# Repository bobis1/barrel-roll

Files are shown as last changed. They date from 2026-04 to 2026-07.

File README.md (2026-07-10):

# barrel-roll

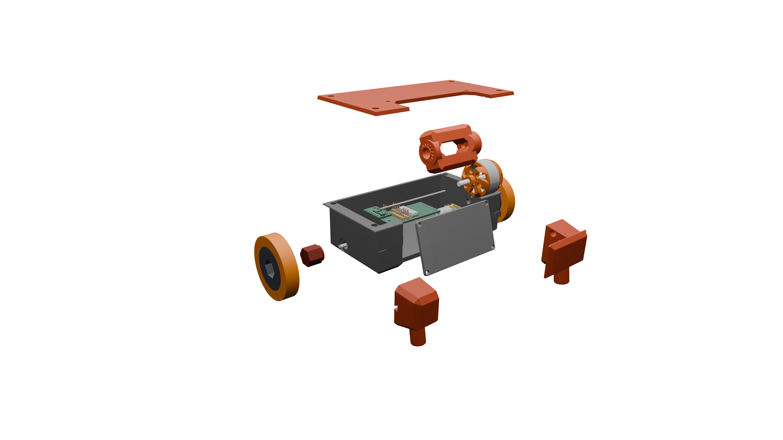
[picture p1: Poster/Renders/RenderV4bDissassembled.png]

_Slightly dissassembled view of barrel roll._

Currently there are some issues with this project
## TODO
- Fix the pcb to have the correct footprint

## What is this
Barrel roll is a 150g combat robot that has a 2.706693 inch long bar spinner. There are two options for the microcontroller of the robot. Right now I have a pcb designed with a RP2040 in mind. I also have a version of the schematic/firmware with an esp32 as the microcontroller.

## Why I created this
I created barrel roll because the way I got into robotics/programming/stem in general is through watching various battlebots-like shows and videos on the internet. So for a long time, I wanted to create my own battle bot. Once I saw the Fallout event by Hack Club I decided that it would be an amazing opportunity to create something similar to what got me into this in the first place. My goal with barrel roll is to create a bar spinner battle bot that could compete in the 150g weight class.(not necessarily well)

## PCB
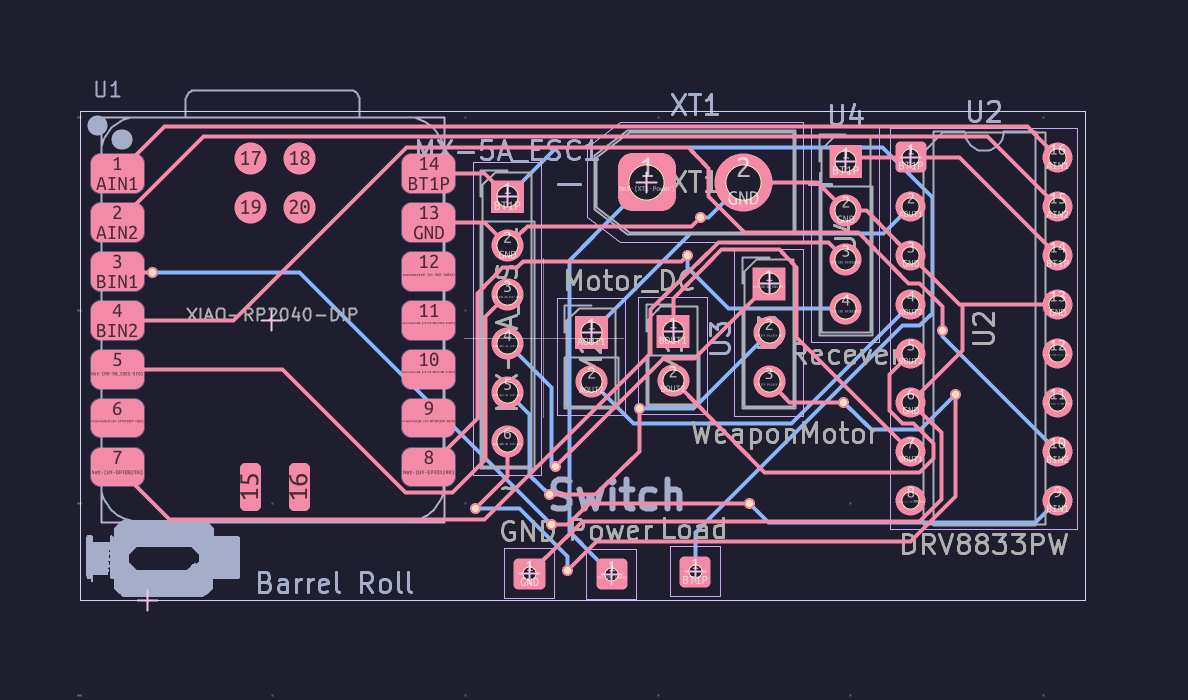
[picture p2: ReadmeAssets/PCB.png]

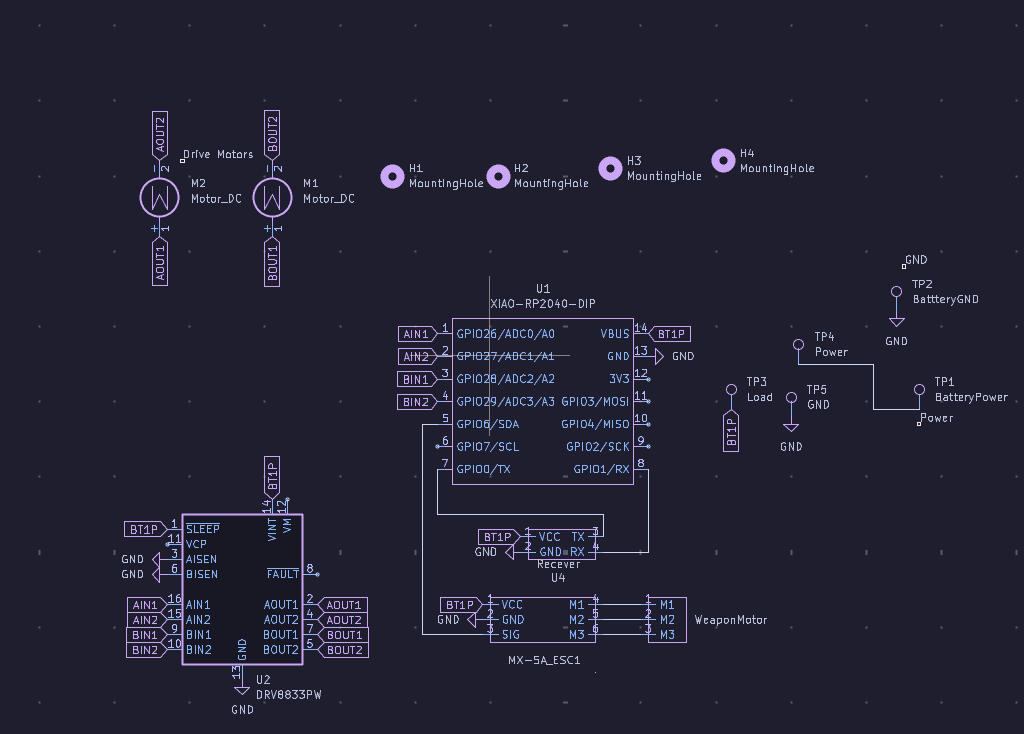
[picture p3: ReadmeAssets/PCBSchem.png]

Above are the images of the PCB version of the electrical components of the robot(To be honest right now it feels more like a glorified pinout board)

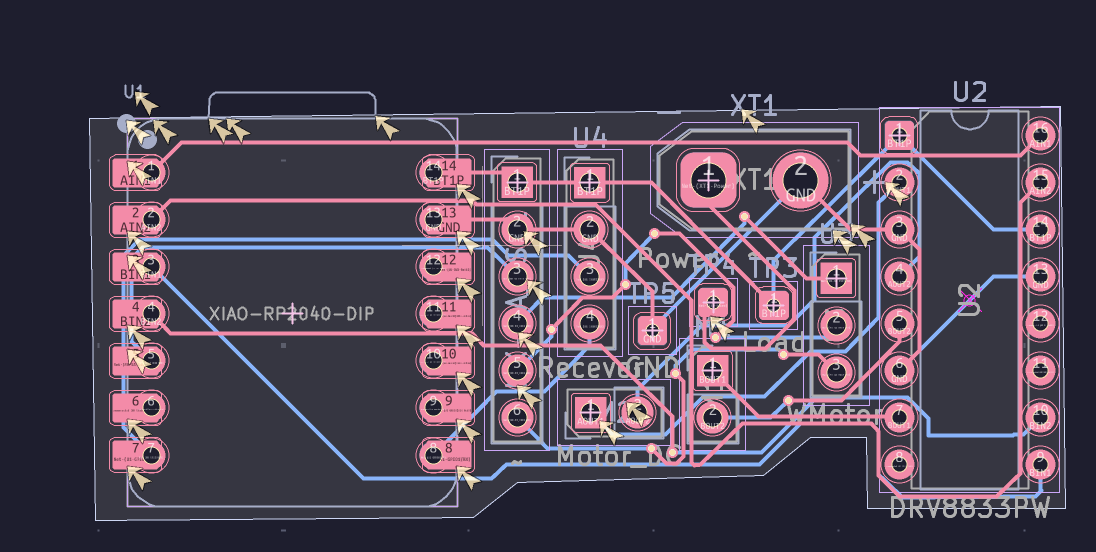
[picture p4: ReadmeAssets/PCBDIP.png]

Above is a picture of the pcb using DIP sodering. The schematic is the same as the original SMD sodered PCB.

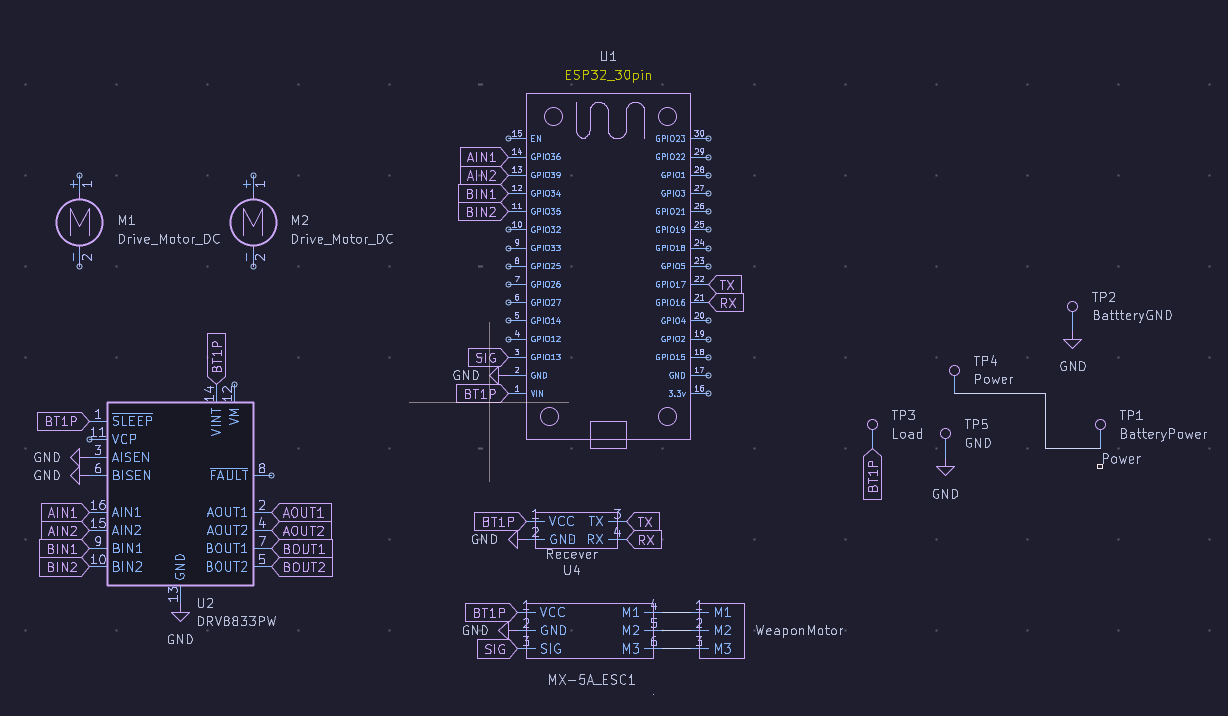
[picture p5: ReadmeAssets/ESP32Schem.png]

The above is a picture of the schematic for anyone using the DOIT esp32 devkit v1. I made this one because it could cut down on the cost of the project as a whole.

## Assembly
Onshape link: https://cad.onshape.com/documents/4d0cf8c11fd66439fc3e30b0/w/a8064dfad10d7d33689fe150/e/62081654516d84e6ca0ee160
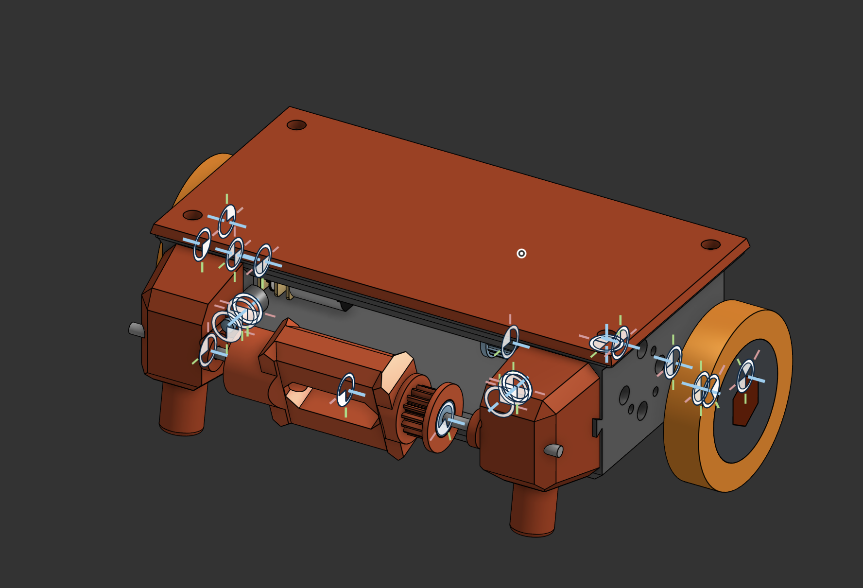
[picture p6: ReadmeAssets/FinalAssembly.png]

A note about the assembly: I could not find 3d models of the bearings I wanted to use so I made a model with the same dimensions as the bearings. /n

As a note I intend on using the PCB SMD BOM.

### PCBs/Electronics
For this project I made several usable versions of the electronics. I did this to make sure that when it comes time for me to actually build this I can still build it even if I don't have some of the equipment that I need. The main distinction between all of the options are the different ways to soder on the microcontroller. For the no pcb method you could just use an esp32 instead of a xiao rp2040.

#### PCB SMD
IF you are using a PCB to create Barrel Roll then you need to get the Gerbers.zip from barrel-roll folder in the repo. After this you need to go to your preferred PCB manufacteror of your choice to have it manufactured.  [Gerbers.zip](barrel-roll-pcb/Gerbers.zip)
You could use [this](https://fabacademy.org/2024/labs/charlotte/students/richard-shan/lessons/week4/rp2040/) as a reference for SMD sodering the xiao RP2040.

#### PCB DIP
If you are using the DIP version of the pcb then you need to follow many of the same steps as using the SMD pcb method. However, since you are using DIP for the RP2040, sodering the PCB should be significantly simpler. [Gerbers.zip](barrel-roll-DIPPCB/Gerbers.zip)

#### No PCB
If you are not using a PCB your costs will be a little bit lower since you don't need to by the PCB. To find the wiring diagram you can look in the barrel-roll-nopcb folder of the repo. This is a kicad project that contains a wiring diagram if you have a DOIT ESP32 devkit 1(The esp32 from the electronics kits that commonly come from hackclub events).

#### Assembling the weapon system shell
In order to assemble the weapon system properly you want to make sure that you place the parts on the axle in the correct order. Axle stopper, Weapon with bearing, Axle stopper. Then you need to place the axle onto the two pieces on the Side shell.
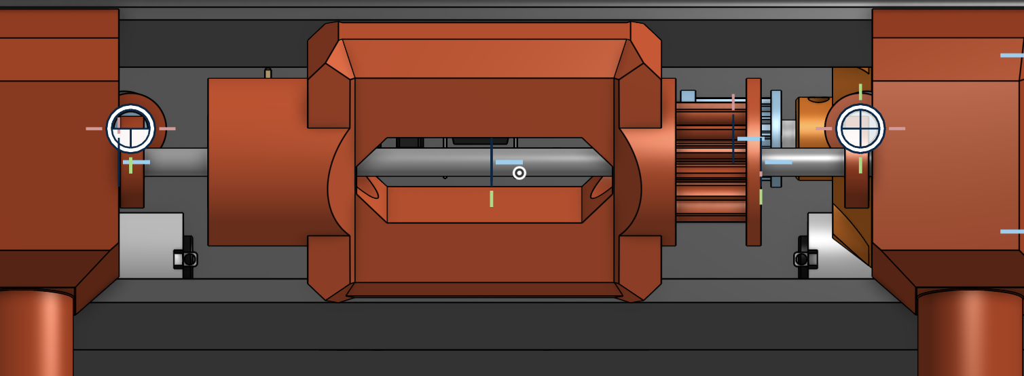
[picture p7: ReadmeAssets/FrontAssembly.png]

Here is a picture of the front assembly that you should try to replicate.

#### 3D printing
To assemble the barrel-roll you first need to print out the parts specified in the onshape document. All the parts in the FINAL folder must be printed There will be a note with the quantity and the infill amount. The fillament for all of these will be up to you. I will personally be using TPU. If you do not want to go into the Onshape, All of the final .step files will be in [models/FinalParts](CAD/V5).\

 You need to print:
* 1 BodyFinalPart1.step [Link](CAD/V5/BodyFinalPart1.step)
* 1 BodyFinalPart2.step [Link](CAD/V5/BodyFinalPart2.step)
* 2 n20motorToWheel.step [Link](CAD/V5/n20motorToWheel.step)
* 1 ShaftCap [Link](CAD/V5/ShaftCapFinal.step)
* 1 WeaponDirectDrive.step [Link](CAD/V5/WeaponDirectDrive.step)
* Weapon Cap [Link](CAD/V5/WeaponMotorCap.step)

#### Assembling the shell
##### For context:
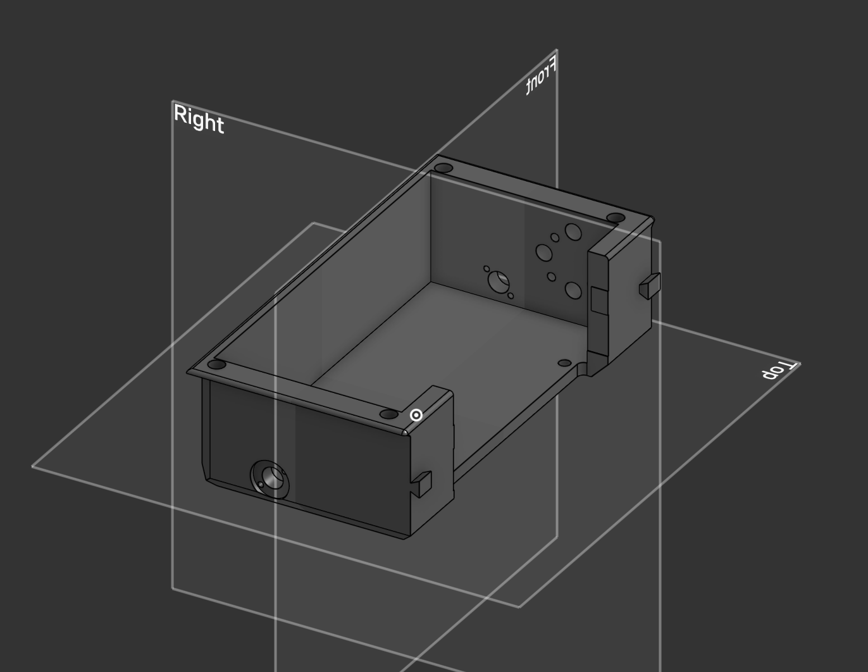
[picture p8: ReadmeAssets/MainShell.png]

[.Step File](CAD/V5/BodyFinalPart1.step)
The above is the main shell
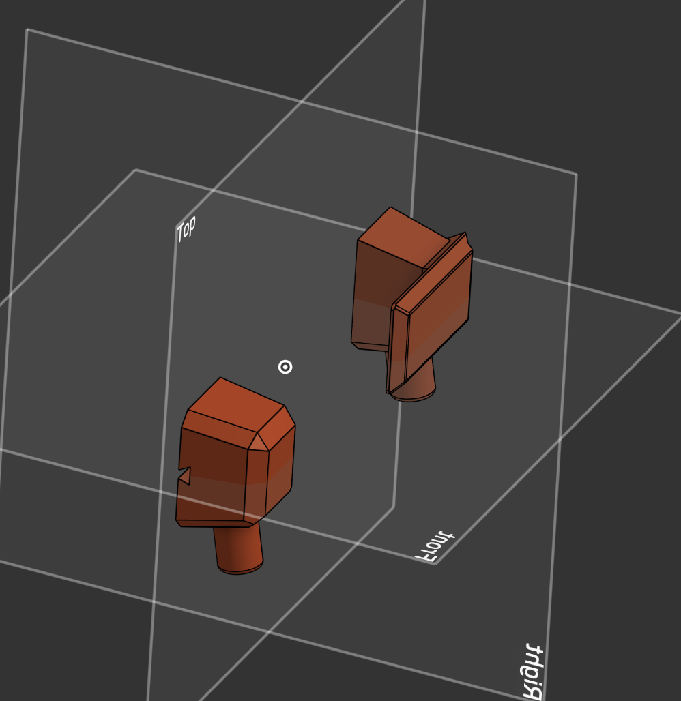
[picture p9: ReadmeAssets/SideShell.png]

[.Step File](CAD/V5/BodyFinalPart2.step)

The above is the side shell
For the rest of it you should look at the onshape document.

To assemble the Main shell with the Side Shells you can use the bowtie connector along side the fastening rod to attach each part of the SIDE_SHELL without the use of metal connectors. To do this, follow the instructions below.

- 1. you first need to slide the shell into place directly into the bowtie connector. The next thing you want to do is slot in the pin connectors into the respective hole.
 [video](ReadmeAssets/SideAssembly1.mov). (Yes I knbow the video is outdated I made the video before making a bunch of design changes relating to the side shell.)

- 2. After this you want to slide the shaft onto the side piece. The next thing that you want to do is attach a shaft cap directly on the inside of the side shell. [video](ReadmeAssets/ShaftAssembly1.mov). 

- 3. You need to slide the weapon onto the shaft. Next you need to slide the other shaft cap onto the shaft.
[video](ReadmeAssets/ShaftAssembly2.mov). After you do this you need to attach the belt to the timing wheel of the weapon.

- 4. The next thing that you need to do is you need to repeat step 1 for the other side of the case. With this you are finished with the shell assembly.

#### Assembling the weapon motor system
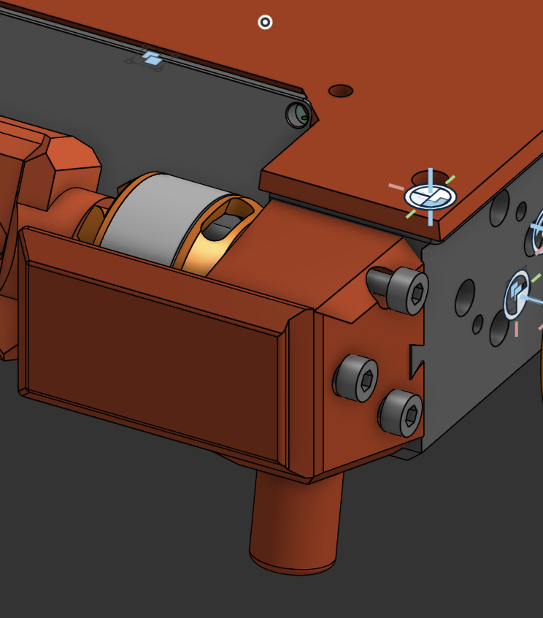
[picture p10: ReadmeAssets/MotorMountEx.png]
motorMountAssembly
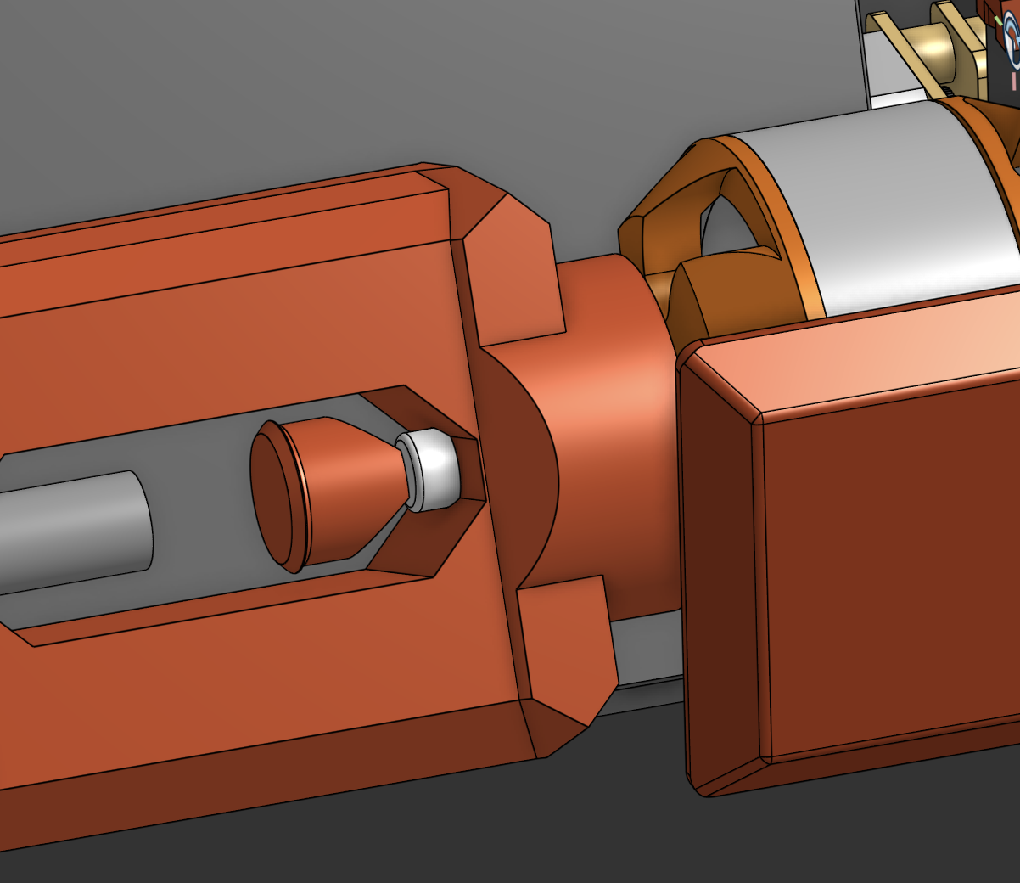
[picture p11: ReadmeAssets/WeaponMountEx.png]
WeaponAssembly
Assemblint the weapon system involves, using the weapon motor screws to secure the motor to the side of the shell with the "shield" like so . Next to finish securing the weapon onto the motor, simply slide the weapon onto the motor shaft then place the cap onto the motor shaft like so .
With this you are almost done with the weapon motor system. n/

The next thing that you need to do is slide the shaft into the bearings. Before doing this you need to cut the (90mm) shaft into a 60mm shaft.(The reason for this is to cut down on the weight and to to make the shaft super long.) An alternative to this would be to print out a similarly sized rod out of ABS or petg [Here](CAD/V5/shaft.step)

#### Electronics
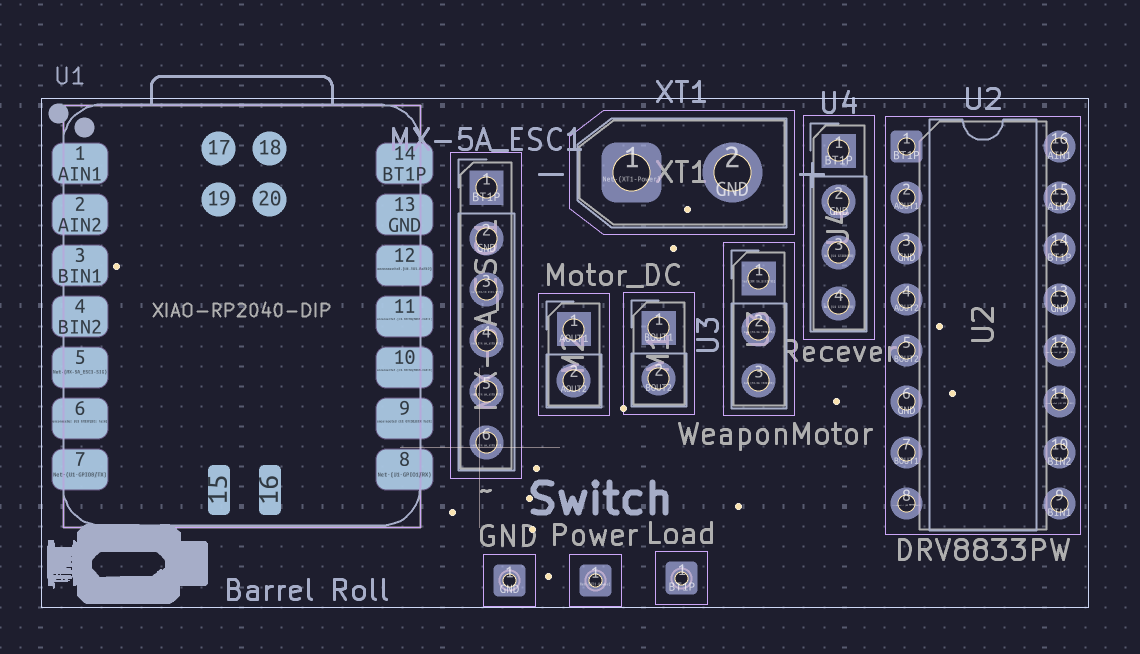
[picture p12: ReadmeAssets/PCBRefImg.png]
PCB image
For the electronics you want to reference the [Schematic](ReadmeAssets/barrel-roll.pdf) and the . First you want to wire the drive motors to AOUT and BOUT pin holes respectively. Do this for both of the drive motors. The next thing that you want to do is attach the motor driver to the respective pins. Next you have to attach the ESC motor controller for the brushless motor. Next you have to soder the jumper wires to their respective ports based on the schematic of the pcb. The schematic should have all the pins that you need to soder to.

## Usage
To use barrel roll you need to connect the radio recever to the radio sender.
After this you should be able to control the robot using your controller.

## BOM
There are three BOMs one for SMD, DIP and one if you are simply using a esp32.
The "master" BOM can be found here [BOM](ReadmeAssets/BOM.csv)(This will be the most convienient to use and will be the most updated in the coming months.)
### BOM for PCB
 [Here is the .csv for the BOM](ReadmeAssets/BarrelRollerBOM.csv)
### BOM if you are not using a PCB
 [Here is the .csv for the BOM](ReadmeAssets/BarrelRollerBOMnopcb.csv)
### BOM PCB-DIP
 [Here is the .csv for the BOM](ReadmeAssets/BarrelRollerBOMDIP.csv)

## Poster
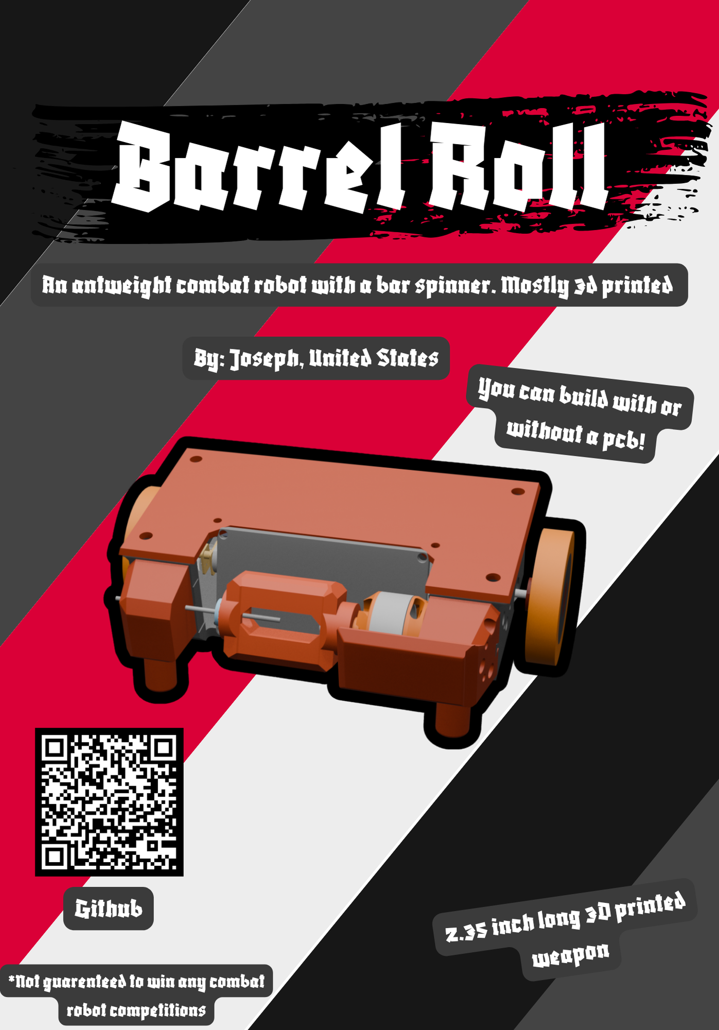
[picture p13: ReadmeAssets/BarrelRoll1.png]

[Poster](Poster/Barrel%20Roller.pdf)

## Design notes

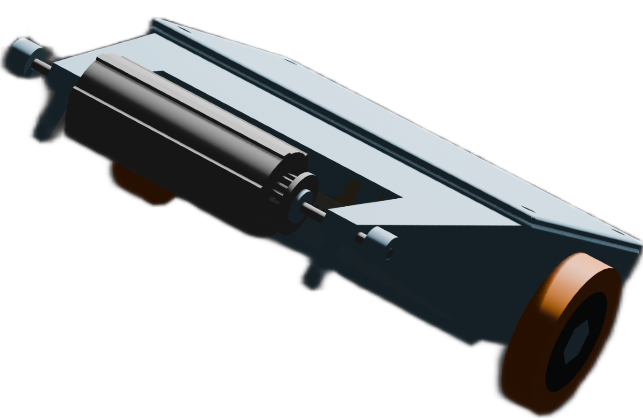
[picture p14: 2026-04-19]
Poster/Renders/FinalRenderNoback.png

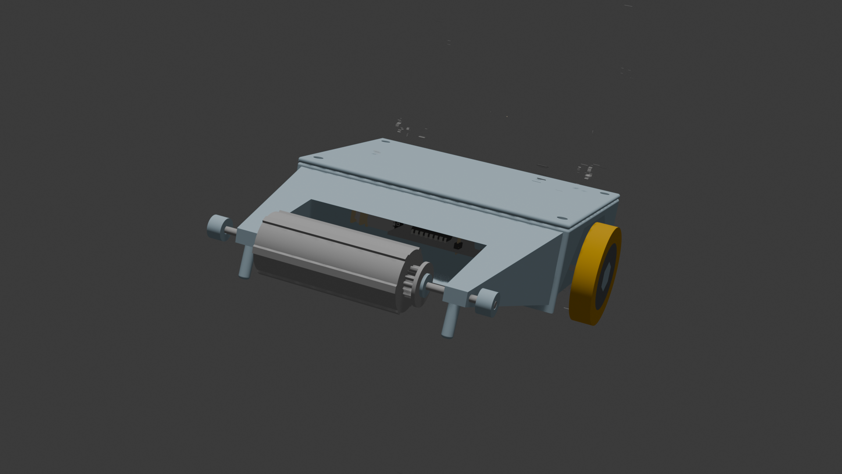
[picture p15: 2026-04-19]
Poster/Renders/DraftRender1.png

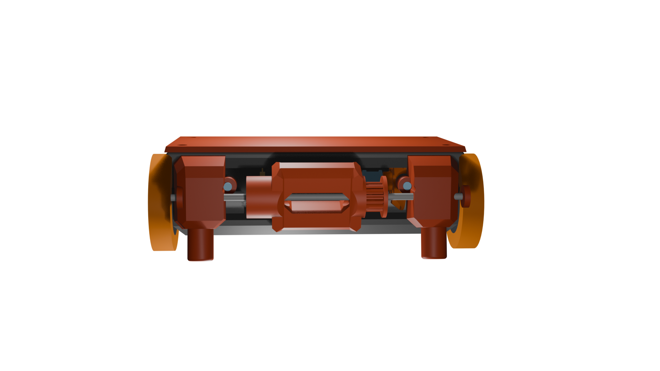
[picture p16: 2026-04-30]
Poster/Renders/RenderV2.png

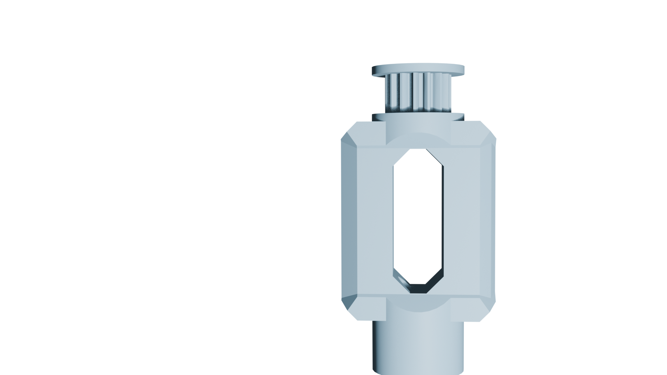
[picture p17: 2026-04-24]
Poster/Renders/PCBWeaponRender1.png

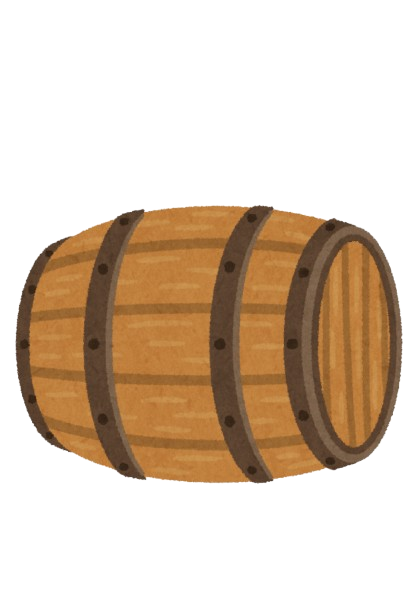
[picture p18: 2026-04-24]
Poster/assets/Barrel_Roller__1_-removebg-preview.png

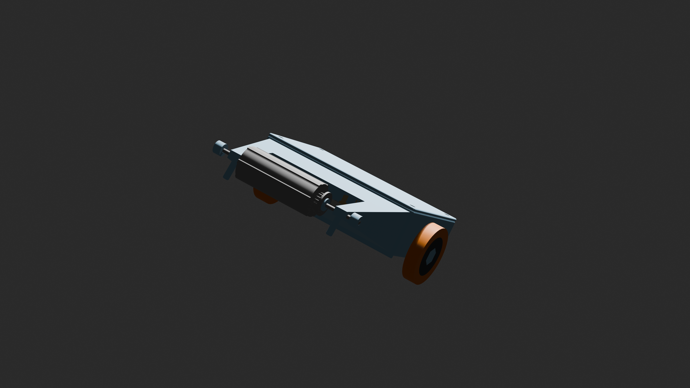
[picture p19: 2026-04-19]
Poster/Renders/FinalRender.png

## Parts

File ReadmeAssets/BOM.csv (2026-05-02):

Barrel-roll-SMDPCB
Reference | Qty | Part | Footprint | Supplier | Unit Price | Total Price | Weight | SubTotal: | $234.90
U1 | 1 | XIAO-RP2040-DIP | Seeed Studio XIAO Series Library:XIAO-RP2040-DIP | https://www.seeedstudio.com/XIAO-RP2040-v1-0-p-5026.html | $3.99 | $3.99 |  | Shipping: | $35.37
U2 | 1 | DRV8833PW | Package_DIP:DIP-16_W7.62mm | https://www.pololu.com/product/2130/resources | $10.95 | $10.95 |  | Tax: | $4.05
U3 | 1 | WeaponMotor | Connector_PinHeader_2.54mm:PinHeader_1x03_P2.54mm_Vertical | https://itgresa.com/product/d2822-8-brushless-motor-outrunner/ | $15.49 | $15.49 |  | Total: | $274.32
U4 | 1 | Recever | Connector_PinHeader_2.54mm:PinHeader_1x04_P2.54mm_Vertical | https://radiomasterrc.com/collections/elrs-receivers/products/xr1-nano-multi-frequency-expresslrs-receiverr | $11.99 | $11.99 |  | Hours Required: | 54.86
n/a | 2 | Bearings | n/a | https://www.aliexpress.us/item/2271799817221155.html?curPageLogUid=5TuNOIFeizbl | $0.65 | $1.30
n/a | 1 | Shaft | n/a | https://www.aliexpress.us/item/3256805290944526.html?curPageLogUid=UdRs5Z1uZKiS | $0.99 | $0.99
n/a | 1 | Heatset Inserts | n/a | https://www.aliexpress.us/item/3256807895940353.html?curPageLogUid=BxN9cLGVkdYJ | $0.99 | $0.99
n/a | 1 | LIPO battery | Connector_Wire:SolderWire-2sqmm_1x01_D2mm_OD3.9mm | https://www.racedayquads.com/products/rdq-series-11-4v-3s-720mah-100c-lihv-whoopmicro-battery-xt30 | $18.49 | $18.49
XT1 | 1 | XT60 | Connector_AMASS:AMASS_XT30UPB-F_1x02_P5.0mm_Vertical | https://www.pololu.com/product/2175 | $2.95 | $2.95
n/a | 2 | N20 Motor | dc_motor | https://www.aliexpress.us/item/2255800106854951.html?curPageLogUid=DiJwBbgZZ32D | 0.99 | $1.98
n/a | 1 | PCB | n/a | n/a | $2.10 | $2.10
n/a | 1 | Weapon Motor Screws | n/a | https://www.homedepot.com/p/Everbilt-M3-0-5-x-12mm-Zinc-Flat-Head-Phillips-Drive-Machine-Screw-4-Pieces-837751/321071710 | $1.95 | $1.95
n/a | 4 | Drive Motor Screw | n/a | https://www.metricscrews.us/index.php?main_page=product_info&cPath=98_290_337&products_id=1240 | $0.65 | $2.60
n/a | 1 | Timing Belt | n/a | https://www.aliexpress.us/item/3256806230097622.html?curPageLogUid=Dl3947EX6SHI | $3.23 | $3.23
Barrel-roll-DIPPCB
Reference | Qty | Part | Footprint | Supplier | Unit Price | Total Price | Weight | SubTotal: | $155.90
U1 | 1 | XIAO-RP2040-DIP | Seeed Studio XIAO Series Library:XIAO-RP2040-DIP | https://www.seeedstudio.com/XIAO-RP2040-v1-0-p-5026.html | $3.99 | $3.99 |  | Shipping: | $35.37
U2 | 1 | DRV8833PW | Package_DIP:DIP-16_W7.62mm | https://www.pololu.com/product/2130/resources | $10.95 | $10.95 |  | Tax: | $4.05
U3 | 1 | WeaponMotor | Connector_PinHeader_2.54mm:PinHeader_1x03_P2.54mm_Vertical | https://itgresa.com/product/d2822-8-brushless-motor-outrunner/ | $15.49 | $15.49 |  | Total: | $195.32
U4 | 1 | Recever | Connector_PinHeader_2.54mm:PinHeader_1x04_P2.54mm_Vertical | https://radiomasterrc.com/collections/elrs-receivers/products/xr1-nano-multi-frequency-expresslrs-receiverr | $11.99 | $11.99 |  | Hours Required: | 39.06
n/a | 2 | Bearings | n/a | https://www.aliexpress.us/item/2271799817221155.html?curPageLogUid=5TuNOIFeizbl | $0.65 | $1.30
n/a | 1 | Shaft | n/a | https://www.aliexpress.us/item/3256805290944526.html?curPageLogUid=UdRs5Z1uZKiS | $0.99 | $0.99
n/a | 1 | Heatset Inserts | n/a | https://www.aliexpress.us/item/3256807895940353.html?curPageLogUid=BxN9cLGVkdYJ | $0.99 | $0.99
n/a | 1 | LIPO battery | Connector_Wire:SolderWire-2sqmm_1x01_D2mm_OD3.9mm | https://www.racedayquads.com/products/rdq-series-11-4v-3s-720mah-100c-lihv-whoopmicro-battery-xt30 | $18.49 | $18.49
XT1 | 1 | XT60 | Connector_AMASS:AMASS_XT30UPB-F_1x02_P5.0mm_Vertical | https://www.pololu.com/product/2175 | $2.95 | $2.95
n/a | 2 | N20 Motor | dc_motor | https://www.aliexpress.us/item/2255800106854951.html?curPageLogUid=DiJwBbgZZ32D | 0.99 | $1.98
n/a | 1 | PCB | n/a | n/a | $2.10 | $2.10
n/a | 1 | Weapon Motor Screws | n/a | https://www.homedepot.com/p/Everbilt-M3-0-5-x-12mm-Zinc-Flat-Head-Phillips-Drive-Machine-Screw-4-Pieces-837751/321071710 | $1.95 | $1.95
n/a | 4 | Drive Motor Screw | n/a | https://www.metricscrews.us/index.php?main_page=product_info&cPath=98_290_337&products_id=1240 | $0.65 | $2.60
n/a | 1 | Timing Belt | n/a | https://www.aliexpress.us/item/3256806230097622.html?curPageLogUid=Dl3947EX6SHI | $3.23 | $3.23
Barrel-roll-nopcb
Reference | Qty | Part | Footprint | Supplier | Unit Price | Total Price |  | SubTotal: | $76.91
U1 | 1 | XIAO-RP2040-DIP | DOIT Esp32 devkit v1 | https://www.aliexpress.us/item/3256805168037961.html?curPageLogUid=5MpwdTl1HOht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 | $4.00 | $4.00 |  | Shipping: | $35.37
U2 | 1 | DRV8833PW | Package_DIP:DIP-16_W7.62mm | https://www.pololu.com/product/2130/resources | $10.95 | $10.95 |  | Tax: | $4.05
U3 | 1 | WeaponMotor | Connector_PinHeader_2.54mm:PinHeader_1x03_P2.54mm_Vertical | https://itgresa.com/product/d2822-8-brushless-motor-outrunner/ | $15.49 | $15.49 |  | Total: | $116.33
U4 | 1 | Recever | Connector_PinHeader_2.54mm:PinHeader_1x04_P2.54mm_Vertical | https://radiomasterrc.com/collections/elrs-receivers/products/xr1-nano-multi-frequency-expresslrs-receiverr | $11.99 | $11.99 |  | Hours Required: | 23.27
n/a | 2 | Bearings | n/a | https://www.aliexpress.us/item/2271799817221155.html?curPageLogUid=5TuNOIFeizbl | $0.65 | $1.30
n/a | 1 | Shaft | n/a | https://www.aliexpress.us/item/3256805290944526.html?curPageLogUid=UdRs5Z1uZKiS | $0.99 | $0.99
n/a | 1 | Heatset Inserts | n/a | https://www.aliexpress.us/item/3256807895940353.html?curPageLogUid=BxN9cLGVkdYJ | $0.99 | $0.99
n/a | 1 | LIPO battery | Connector_Wire:SolderWire-2sqmm_1x01_D2mm_OD3.9mm | https://www.racedayquads.com/products/rdq-series-11-4v-3s-720mah-100c-lihv-whoopmicro-battery-xt30 | $18.49 | $18.49
XT1 | 1 | XT60 | Connector_AMASS:AMASS_XT30UPB-F_1x02_P5.0mm_Vertical | https://www.pololu.com/product/2175 | $2.95 | $2.95
n/a | 2 | N20 Motor | dc_motor | https://www.aliexpress.us/item/2255800106854951.html?curPageLogUid=DiJwBbgZZ32D | $0.99 | $1.98
n/a | 1 | Timing Belt | n/a | https://www.aliexpress.us/item/3256806230097622.html?curPageLogUid=Dl3947EX6SHI | $3.23 | $3.23
n/a | 1 | Weapon Motor Screws | n/a | https://www.homedepot.com/p/Everbilt-M3-0-5-x-12mm-Zinc-Flat-Head-Phillips-Drive-Machine-Screw-4-Pieces-837751/321071710 | $1.95 | $1.95
n/a | 4 | Drive Motor Screw | n/a | https://www.metricscrews.us/index.php?main_page=product_info&cPath=98_290_337&products_id=1240 | $0.65 | $2.60

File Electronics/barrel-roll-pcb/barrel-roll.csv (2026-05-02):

Reference | Qty | Value | DNP | Exclude from BOM | Exclude from Board | Footprint | Datasheet
M1,M2 | 2 | Motor_DC |  |  |  | Connector_PinHeader_2.54mm:PinHeader_1x02_P2.54mm_Vertical
MX-5A_ESC1 | 1 |  |  |  |  | Connector_PinHeader_2.54mm:PinHeader_1x06_P2.54mm_Vertical
TP1 | 1 | BatteryPower |  |  |  | Connector_Wire:SolderWire-2sqmm_1x01_D2mm_OD3.9mm
TP2 | 1 | BattteryGND |  |  |  | Connector_Wire:SolderWire-2sqmm_1x01_D2mm_OD3.9mm
TP3 | 1 | Load |  |  |  | Connector_Wire:SolderWire-0.1sqmm_1x01_D0.4mm_OD1mm
TP4 | 1 | Power |  |  |  | Connector_Wire:SolderWire-0.1sqmm_1x01_D0.4mm_OD1mm
TP5 | 1 | GND |  |  |  | Connector_Wire:SolderWire-0.1sqmm_1x01_D0.4mm_OD1mm
U1 | 1 | XIAO-RP2040-DIP |  |  |  | Seeed Studio XIAO Series Library:XIAO-RP2040-DIP
U2 | 1 | DRV8833PW |  |  |  | Package_DIP:DIP-16_W7.62mm | http://www.ti.com/lit/ds/symlink/drv8833.pdf
U3 | 1 | WeaponMotor |  |  |  | Connector_PinHeader_2.54mm:PinHeader_1x03_P2.54mm_Vertical
U4 | 1 | Recever |  |  |  | Connector_PinHeader_2.54mm:PinHeader_1x04_P2.54mm_Vertical

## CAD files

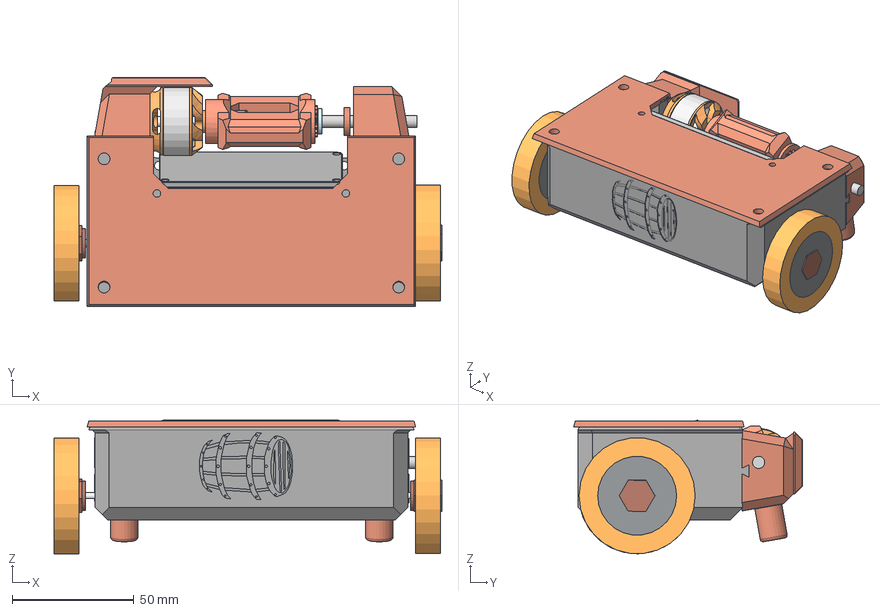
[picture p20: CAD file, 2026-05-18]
CAD/FinalAssembly/FinalAssembly.step
159.1 x 93.8 x 54.9 mm
Bearing
D2822-17 1100KV x 4
Shaft x 2
drv8833-dual-motor-driver-carrier-step
Gear Box x 16
DIP-16_W7.62mm
PinHeader_1x04_P2.54mm_Vertical
40A wheel x 2
WeaponSystem x 2
PinHeader_1x02_P2.54mm_Vertical
WeaponMotorCap
T40 hub x 2
PinHeader_1x02_P2.54mm_Vertical_1
PinHeader_1x03_P2.54mm_Vertical
PinHeader_1x06_P2.54mm_Vertical
Motor x 2
ElectronicsGuard
WeaponV2
LID
barrel-roll_PCB

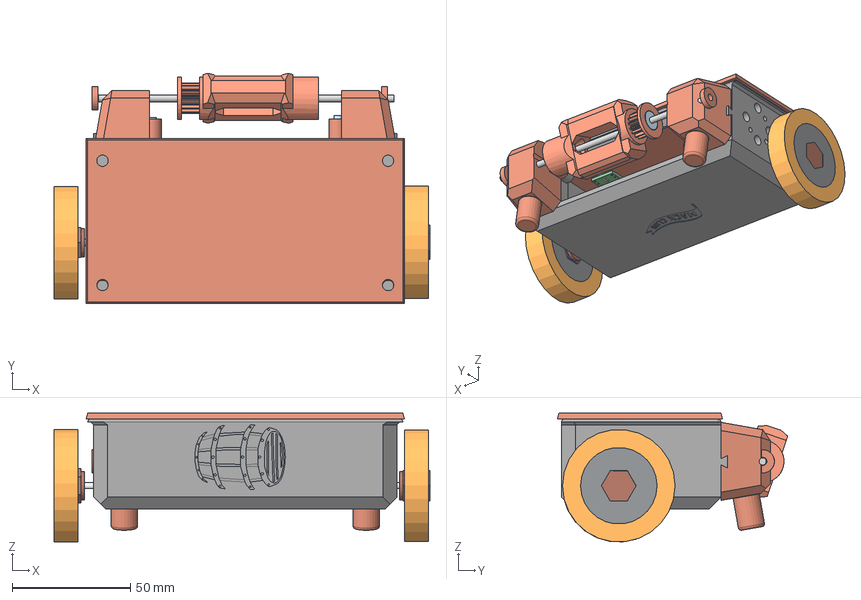
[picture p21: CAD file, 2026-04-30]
CAD/Render/FinalAssembly.step
159.1 x 97.5 x 54.5 mm
Shaft x 2
drv8833-dual-motor-driver-carrier-step
Gear Box x 16
timingwheel
DIP-16_W7.62mm
PinHeader_1x04_P2.54mm_Vertical
D2822-17 1100KV x 5
40A wheel x 2
WeaponSystem x 2
PinHeader_1x02_P2.54mm_Vertical
T40 hub x 2
PinHeader_1x02_P2.54mm_Vertical_1
PinHeader_1x03_P2.54mm_Vertical
PinHeader_1x06_P2.54mm_Vertical
WeaponV2
Motor x 2
LID
barrel-roll_PCB

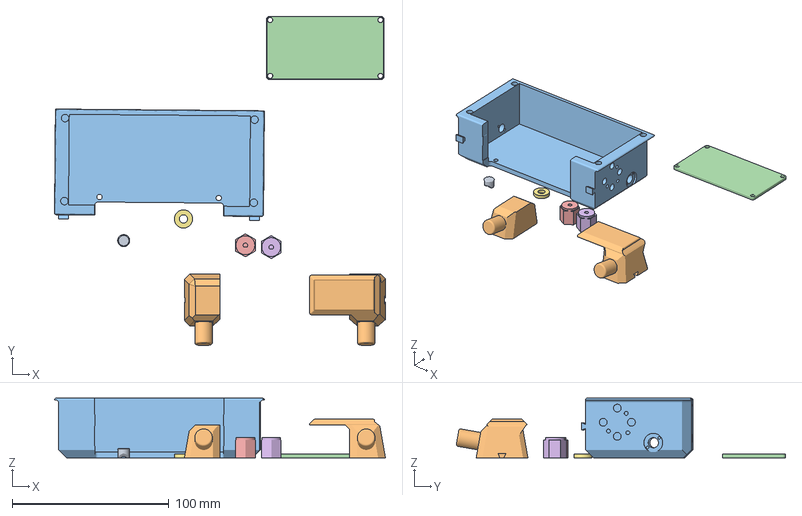
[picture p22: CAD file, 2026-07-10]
CAD/V5/Main.3mf
211.1 x 210.1 x 38.1 mm
WeaponMotorCap.step
BodyFinalPart2.step
BodyFinalPart1.step
ElectronicsGuard.step
n20motorToWheel.step x 2
ShaftCapFinal.step

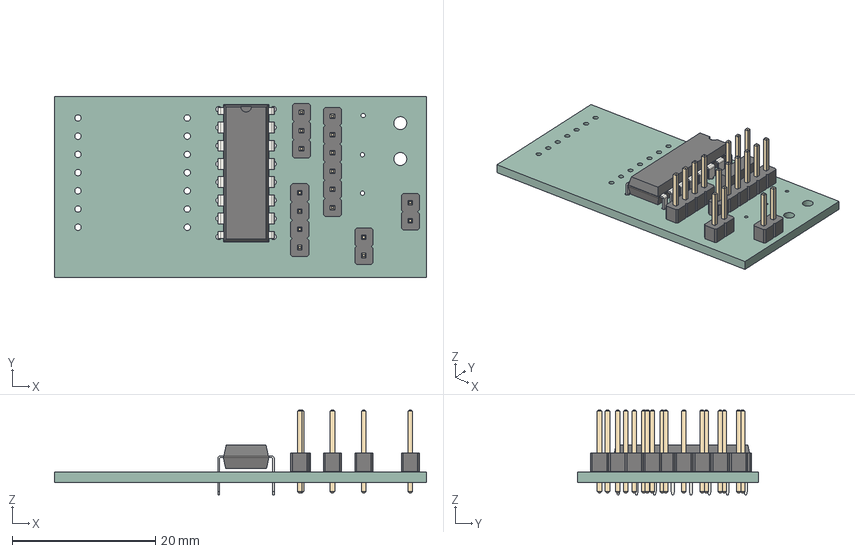
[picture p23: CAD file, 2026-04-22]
Electronics/barrel-roll-pcb/barrel-roll2.step
51.9 x 25.2 x 11.8 mm
PinHeader_1x06_P2.54mm_Vertical
PinHeader_1x03_P2.54mm_Vertical
DIP-16_W7.62mm
PinHeader_1x04_P2.54mm_Vertical
PinHeader_1x02_P2.54mm_Vertical x 2
barrel-roll_PCB

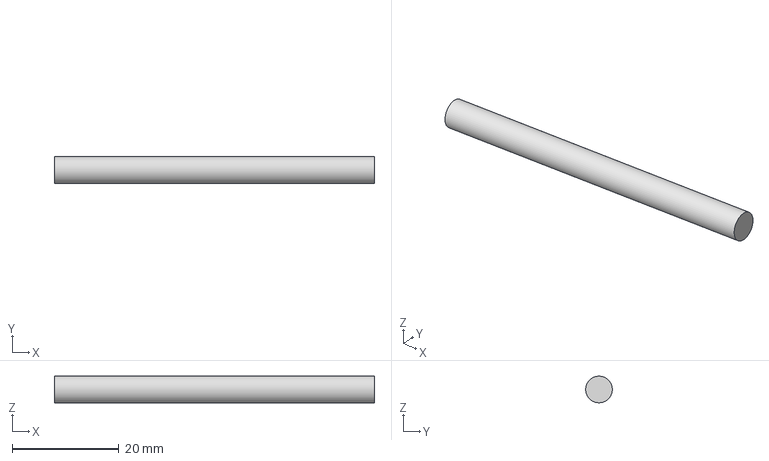
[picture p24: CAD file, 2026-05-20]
CAD/V5/shaft.step
60.0 x 5.00 x 5.00 mm

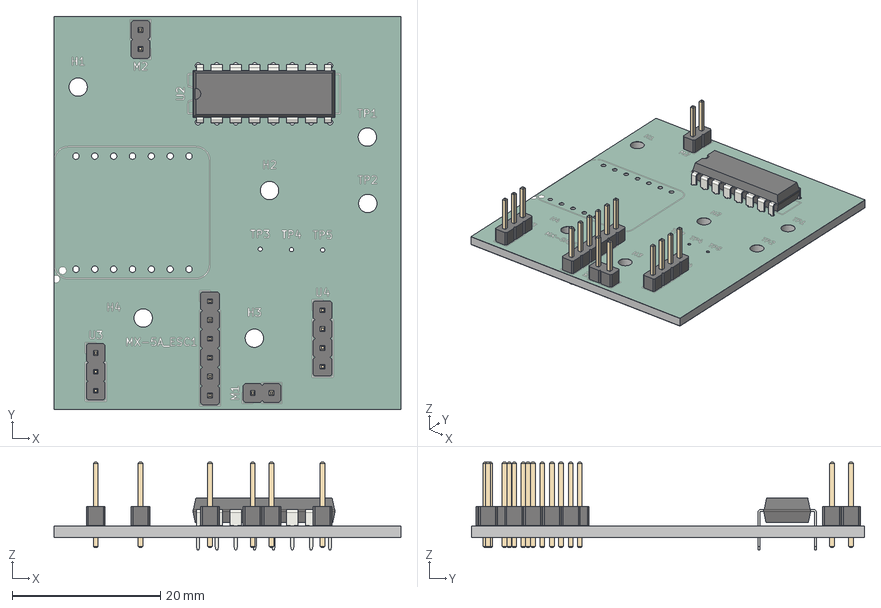
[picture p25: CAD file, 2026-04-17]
Electronics/barrel-roll-pcb/barrel-roll.step
46.7 x 53.0 x 11.8 mm
PinHeader_1x02_P2.54mm_Vertical x 2
PinHeader_1x04_P2.54mm_Vertical
PinHeader_1x03_P2.54mm_Vertical
PinHeader_1x06_P2.54mm_Vertical
DIP-16_W7.62mm
barrel-roll_silkscreen
barrel-roll_soldermask x 2
barrel-roll_PCB

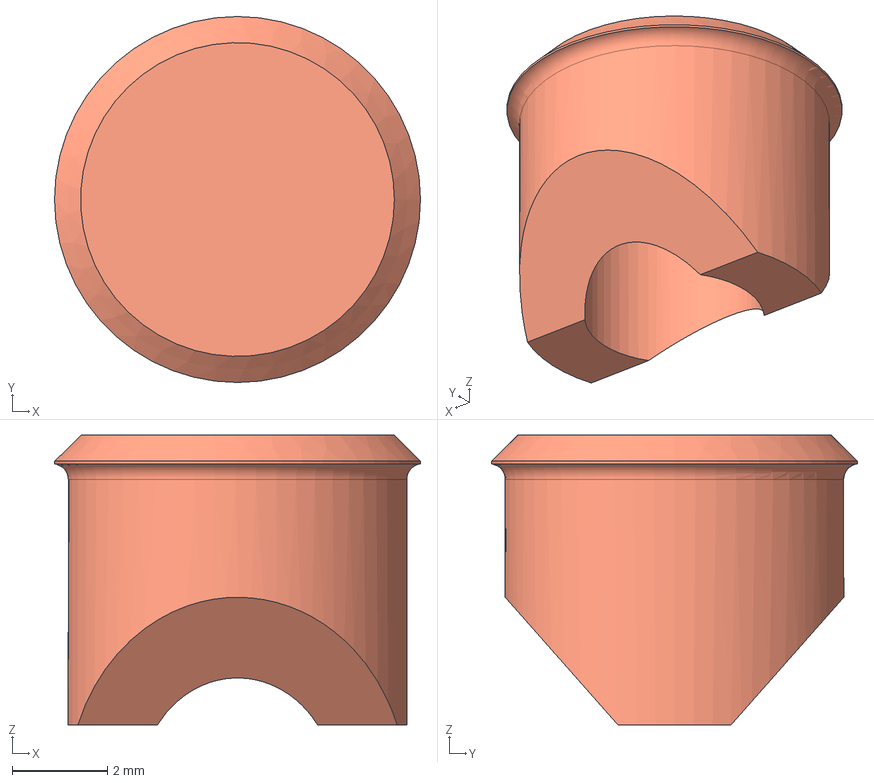
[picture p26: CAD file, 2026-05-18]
CAD/V5/WeaponMotorCap.step
7.70 x 7.70 x 6.10 mm

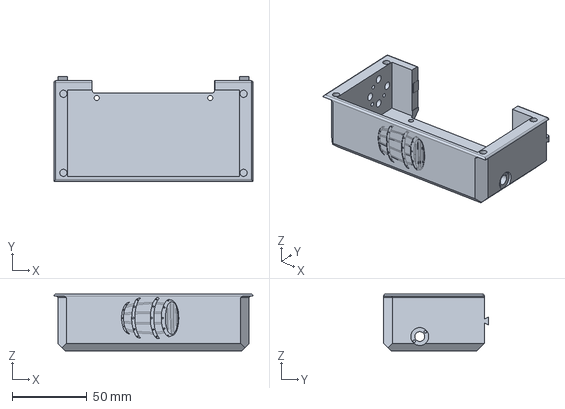
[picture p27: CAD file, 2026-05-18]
CAD/V5/BodyFinalPart1.step
133.3 x 70.1 x 38.1 mm

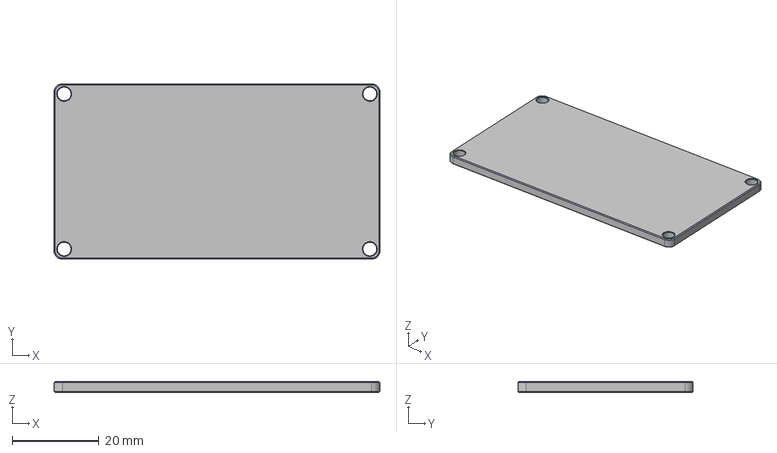
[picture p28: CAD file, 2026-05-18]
CAD/V5/ElectronicsGuard.step
75.0 x 40.3 x 2.50 mm

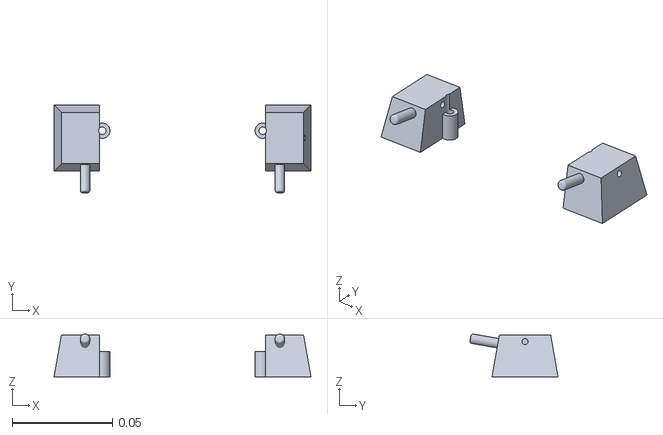
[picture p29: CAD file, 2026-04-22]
CAD/Render/BodyFinalPart2Teeny.stl
0.128 x 0.044 x 0.0214

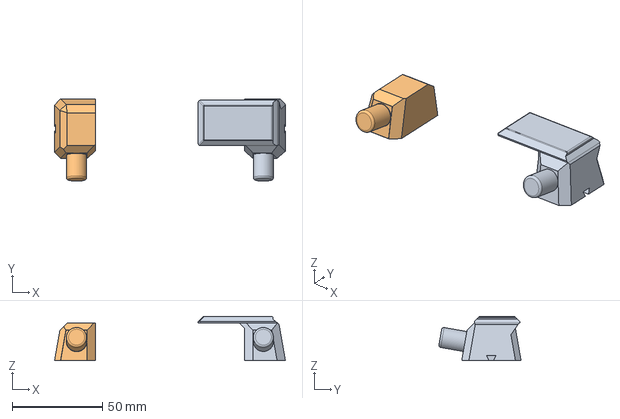
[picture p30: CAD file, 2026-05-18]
CAD/V5/BodyFinalPart2.step
128.3 x 45.7 x 24.7 mm

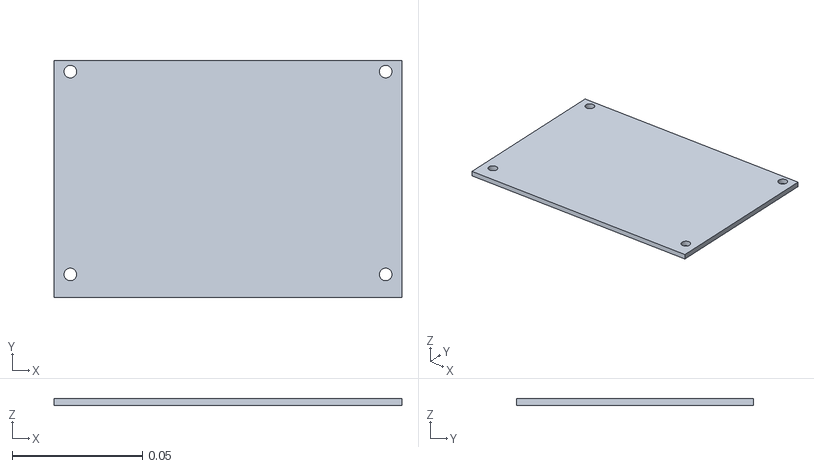
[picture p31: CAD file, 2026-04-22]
CAD/Render/Lid Copy 1EvenLessWeight.stl
0.133 x 0.0907 x 0.00254

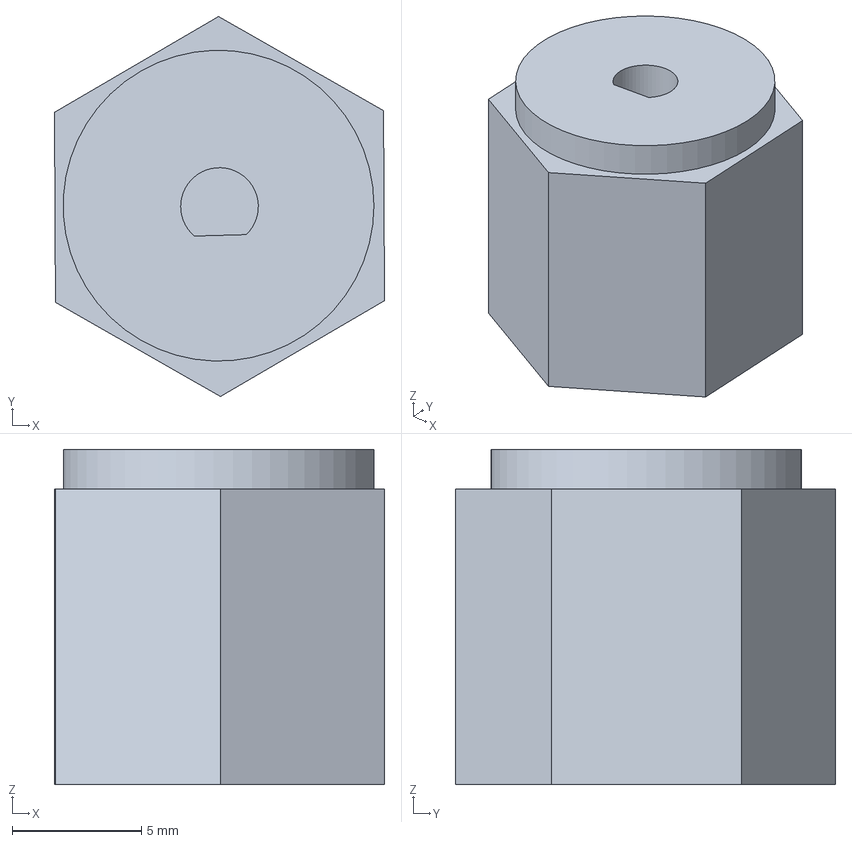
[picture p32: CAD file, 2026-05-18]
CAD/V5/n20motorToWheel.step
12.8 x 14.7 x 13.0 mm

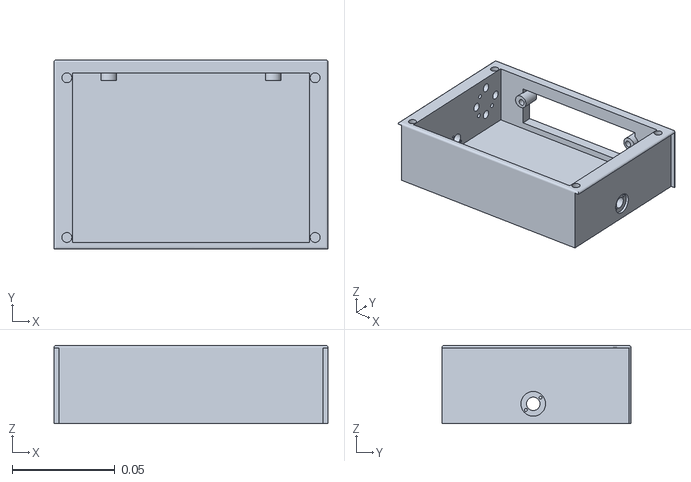
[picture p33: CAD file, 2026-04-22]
CAD/Render/BodyFinalPart1EvenLessWeight.stl
0.133 x 0.0922 x 0.0381

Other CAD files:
CAD/V5/WeaponDirectDrive.step
CAD/Render/WeaponFinalEvenLessWeight.stl
CAD/V5/ShaftCapFinal.step
CAD/Render/n20motorToWheel.stl
CAD/FinalAssembly/FinalAssembly.obj
CAD/Render/FinalAssembly (1).step
CAD/Render/FinalAssembly (2).step
CAD/Render/FinalAssemblyV2 (1).stl
CAD/Render/FinalAssemblyV2.step
CAD/Render/FinalAssemblyV2.stl
CAD/Render/Lid (1).stl
CAD/Render/Lid Copy 1.stl
CAD/Render/Lid.stl
CAD/Render/LightRender.blend
CAD/Render/WeaponMotorTimingWheel.stl
CAD/Render/shaftcap.stl
CAD/V1/BodyDraft3Part1.stl
CAD/V1/BodyDraft3Part2.stl
CAD/V1/BodyFinalPart1.stl
CAD/V1/WeaponDraft.stl
CAD/V2/BodyFinalPart1LessWeight.stl
CAD/V2/BodyFinalPart2.stl
CAD/V2/BodyFinalPart2EvenLessWeight.stl
CAD/V2/BodyFinalPart2LessWeight.stl
CAD/V2/WeaponDraftFinal.stl
CAD/V2/WeaponV2.stl
CAD/V3/BodyFinalPart1Teeny.stl
CAD/V3/WeaponV2Teeny.stl
CAD/V4/BodyFinalPart1.step
CAD/V4/BodyFinalPart2.step
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

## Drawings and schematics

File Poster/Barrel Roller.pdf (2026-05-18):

# Barrel Roll

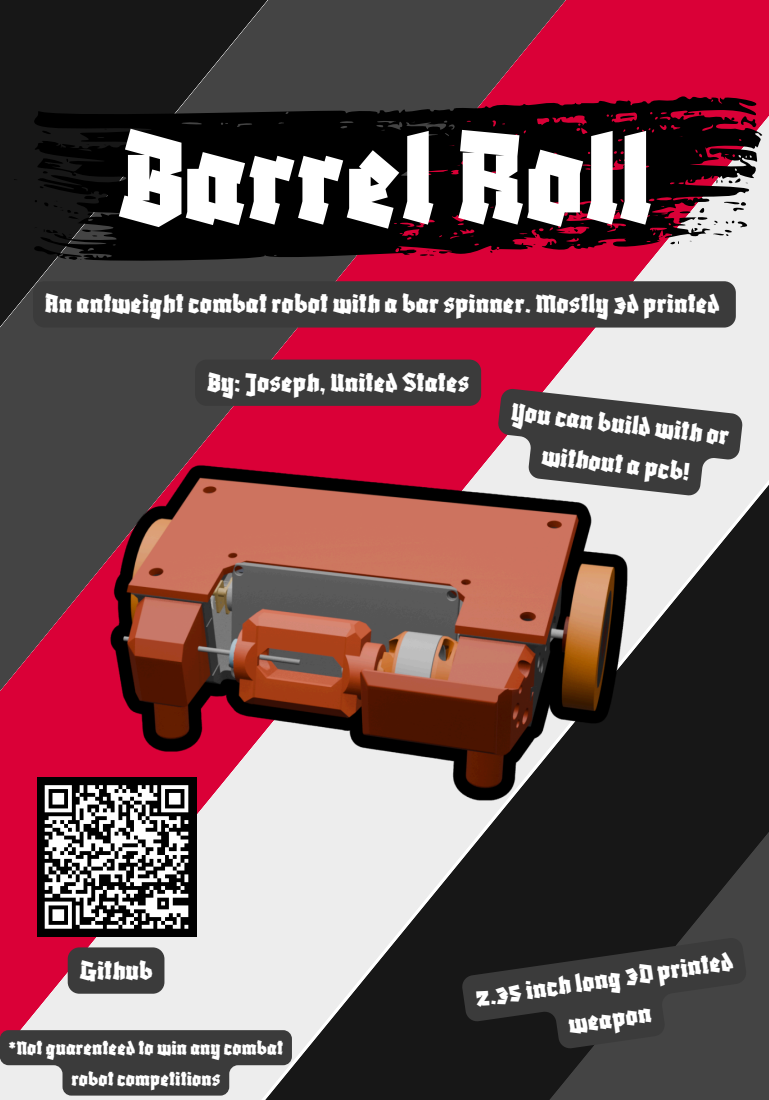
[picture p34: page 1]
Github; without a pcb!; weapon

An antweightcombatrobotwith a barspinner. Mostly 3d printed

By: Joseph, United States

You can buildwith or

2.35 inch long 3D printed

*Not guarenteed towin any combat
robotcompetitions

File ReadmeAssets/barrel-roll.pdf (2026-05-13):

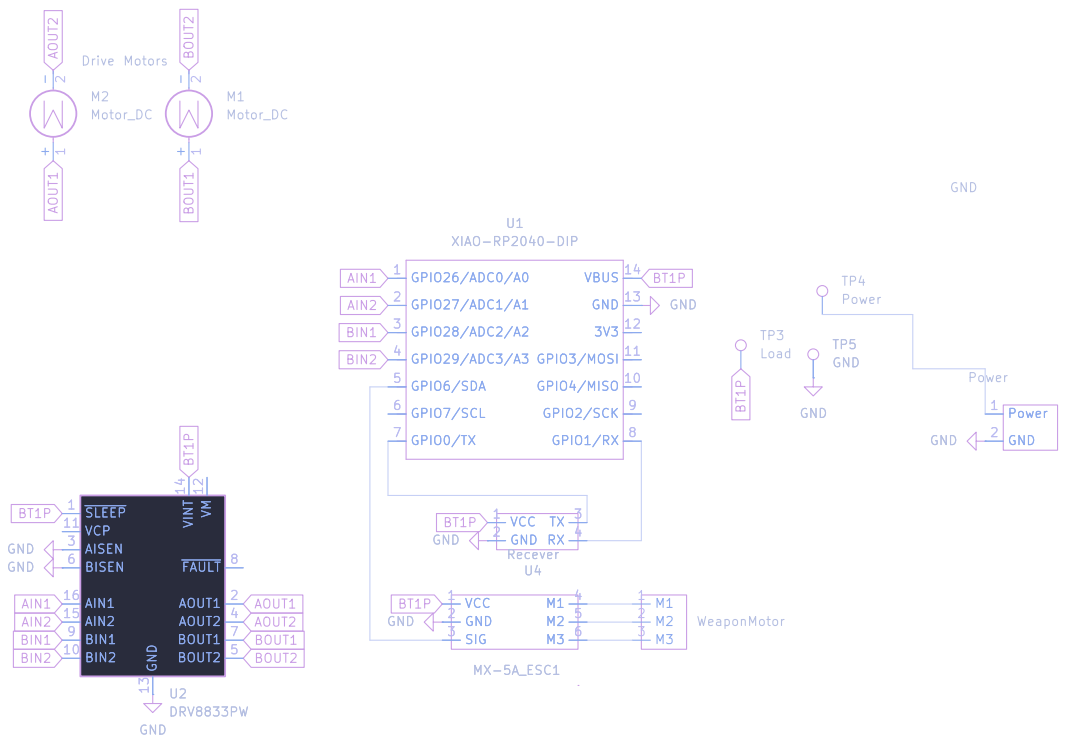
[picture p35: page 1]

Sheet: /
File: barrel-roll.kicad_sch
Title: Barrel Roll Schematic

Size: A4 | Rev: 0
KiCad E.D.A. 10.0.1 | Id: 1/1

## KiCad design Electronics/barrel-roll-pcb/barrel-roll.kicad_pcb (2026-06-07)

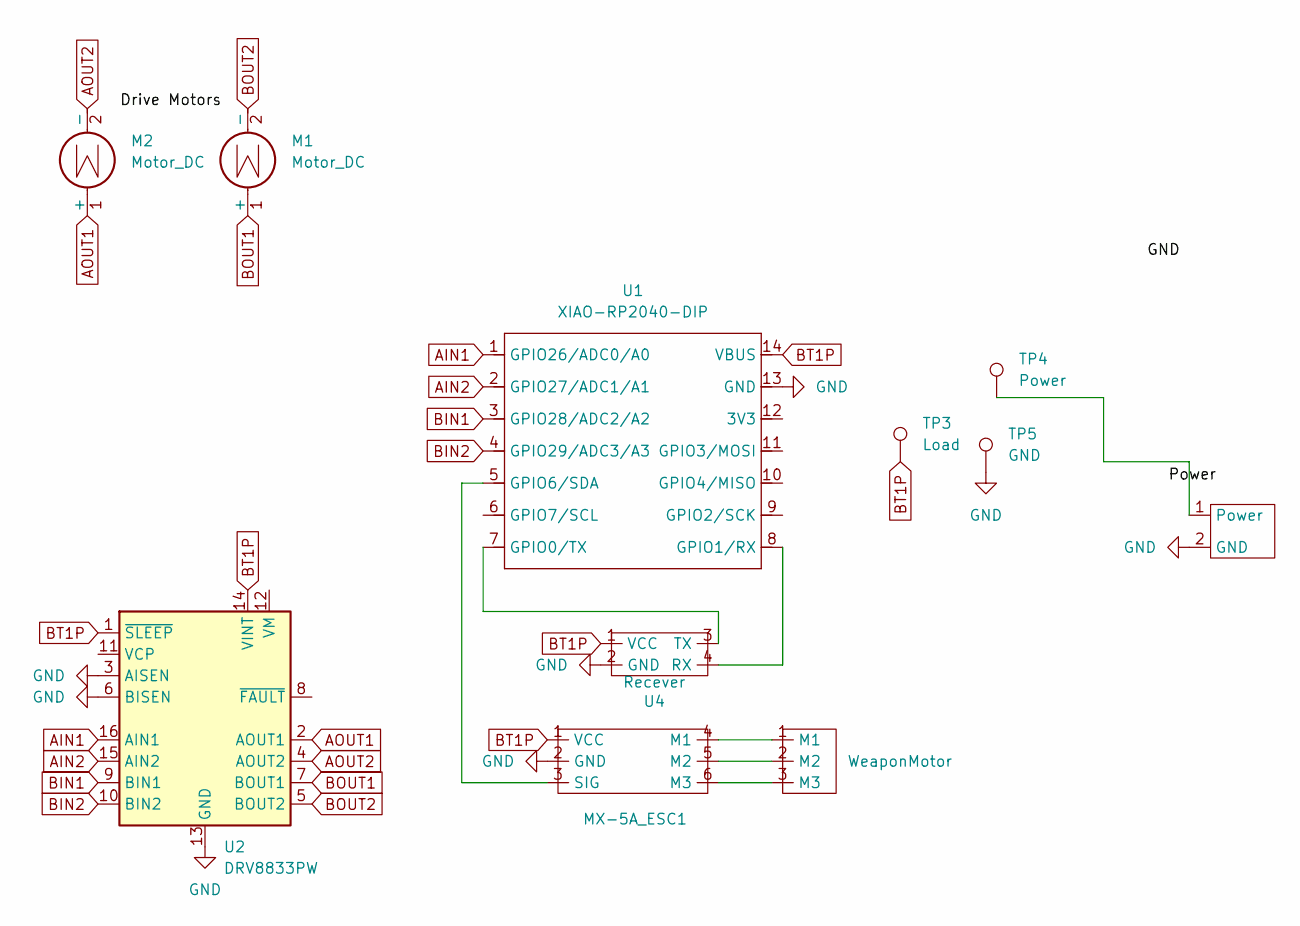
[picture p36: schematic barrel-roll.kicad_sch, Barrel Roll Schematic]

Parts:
M1, M2: Motor_DC; PinHeader_1x02_P2.54mm_Vertical
MX-5A_ESC1: PinHeader_1x06_P2.54mm_Vertical
TP3: Load; SolderWire-0.1sqmm_1x01_D0.4mm_OD1mm
TP4: Power; SolderWire-0.1sqmm_1x01_D0.4mm_OD1mm
TP5: GND; SolderWire-0.1sqmm_1x01_D0.4mm_OD1mm
U1: XIAO-RP2040-DIP; XIAO-RP2040-SMD
U2: DRV8833PW; DIP-16_W7.62mm
U3: WeaponMotor; PinHeader_1x03_P2.54mm_Vertical
U4: Recever; PinHeader_1x04_P2.54mm_Vertical
XT1: AMASS_XT30UPB-F_1x02_P5.0mm_Vertical

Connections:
AIN1: U1.1 (GPIO26/ADC0/A0), U2.16 (AIN1)
AIN2: U1.2 (GPIO27/ADC1/A1), U2.15 (AIN2)
AOUT1: M2.1 (+), U2.2 (AOUT1)
AOUT2: M2.2 (-), U2.4 (AOUT2)
BIN1: U1.3 (GPIO28/ADC2/A2), U2.9 (BIN1)
BIN2: U1.4 (GPIO29/ADC3/A3), U2.10 (BIN2)
BOUT1: M1.1 (+), U2.7 (BOUT1)
BOUT2: M1.2 (-), U2.5 (BOUT2)
BT1P: MX-5A_ESC1.1 (VCC), TP3.1 (1_1), U1.14 (VBUS), U2.1 (~SLEEP), U2.14 (VINT), U4.1 (VCC)
GND: MX-5A_ESC1.2 (GND), TP5.1 (1_1), U1.13 (GND), U2.3 (AISEN), U2.6 (BISEN), U2.13 (GND), U4.2 (GND), XT1.2 (GND)
unnamed: MX-5A_ESC1.4 (M1), U3.1 (M1)
unnamed: MX-5A_ESC1.5 (M2), U3.2 (M2)
unnamed: MX-5A_ESC1.6 (M3), U3.3 (M3)
unnamed: MX-5A_ESC1.3 (SIG), U1.5 (GPIO6/SDA)
unnamed: U1.7 (GPIO0/TX), U4.3 (TX)
unnamed: U1.8 (GPIO1/RX), U4.4 (RX)
unnamed: TP4.1 (1_1), XT1.1 (Power)

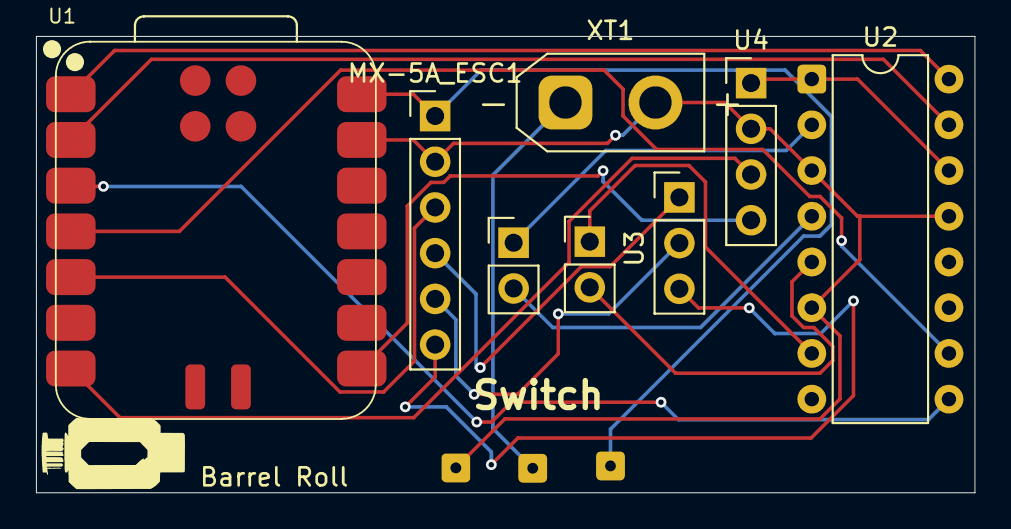
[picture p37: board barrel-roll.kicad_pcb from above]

Board: 2 copper layers, 52.1 x 25.3 mm, 11 parts (0 on the bottom side), 17 nets.

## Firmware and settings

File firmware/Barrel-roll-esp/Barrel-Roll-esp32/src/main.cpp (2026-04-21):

#include <Arduino.h>
#include <AlfredoCRSF.h>
#include <Servo.h>



int driveMotor1Output1 = 36;
int driveMotor1Output2 = 39;
int driveMotor2Output1 = 35;
int driveMotor2Output2 = 34;
int weaponMotorOutput = 13;

float leftJoystickX;
float leftJoystickY;
float rightJoystickX;
float rightJoystickY;
bool isWeaponActive = false;
bool isSpinningForward = true;
Servo weaponMotor;
AlfredoCRSF crsf;

void setup() {
    pinMode(driveMotor1Output1, OUTPUT);
    pinMode(driveMotor1Output2, OUTPUT);
    pinMode(driveMotor2Output1,   OUTPUT);
    pinMode(driveMotor2Output2, OUTPUT);
    weaponMotor.attach(weaponMotorOutput);
    Serial1.begin(420000);
    crsf.begin(Serial1);

}

void loop() {
  crsf.update();
  leftJoystickY = crsf.getChannel(1);
  rightJoystickY = crsf.getChannel(2);
  leftJoystickX = crsf.getChannel(3);
  rightJoystickX = crsf.getChannel(4);
  if(!crsf.isLinkUp()){
    analogWrite(driveMotor1Output2, 0);
    analogWrite(driveMotor1Output1, 0);
    weaponMotor.writeMicroseconds(1000);
    isWeaponActive = false;
    return;
  }
  if (leftJoystickY >= 1600) {
    analogWrite(driveMotor1Output1, 120);
    analogWrite(driveMotor1Output2, 0);
  } else if(leftJoystickY <= 1400){
    analogWrite(driveMotor1Output1, 0);
    analogWrite(driveMotor1Output2, 120);
  } else{
    analogWrite(driveMotor1Output1, 0);
    analogWrite(driveMotor1Output2, 0);
  }
  if(rightJoystickY >= 1600){
    analogWrite(driveMotor2Output1, 120);
    analogWrite(driveMotor2Output2, 0);
  } else if(rightJoystickY <= 1400){
    analogWrite(driveMotor2Output1, 0);
    analogWrite(driveMotor2Output2, 120);
  } else{
    analogWrite(driveMotor2Output1, 0);
    analogWrite(driveMotor2Output2, 0);
  }
  if(leftJoystickX >= 1600){
    isWeaponActive = true;
  } else if (leftJoystickX <= 2000)
  {
    isWeaponActive = false;
  }
  if(rightJoystickX >= 1400){
    isSpinningForward = true;
  } else if (rightJoystickX <= 2000)
  {
    isSpinningForward = false;
  }
  if (isWeaponActive){
    if(isSpinningForward){
      weaponMotor.writeMicroseconds(2000);
    } else{
      weaponMotor.writeMicroseconds(1000);
    }
  }
}

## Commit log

2026-04-12 Got the pcb done.
    [barrel-roll.kicad_pcb, barrel-roll.kicad_sch]
2026-04-17 Worked on the firmware of the bot
    [BodyDraft3Part1.3mf, BodyDraft3Part1.stl, BodyDraft3Part2.stl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]
2026-04-18 Added updated models
    [BodyDraft3Part1.3mf, BodyFinalPart1.stl, BodyFinalPart2.stl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]
2026-04-19 Worked on renders and poster
    [BarrelRoll.blend, FinalAssembly.obj, FinalAssembly.step]
2026-04-21 Added esp32 support, and worked on the battery conenctor.
    [BodyDraft3Part1LessWeight.3mf, BodyFinalPart1 (1).stl, BodyFinalPart1LessWeight.stl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]
2026-04-22 Worked on getting the weights correct.
    [BodyFinalPart1EvenLessWeight.3mf, BodyFinalPart1EvenLessWeight.stl, BodyFinalPart2EvenLessWeight.stl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]
2026-04-22 Updated the pcb and the models.
    [BodyFinalPart1EvenLessWeight.3mf, BodyFinalPart1Teeny.stl, BodyFinalPart2Teeny.stl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]
2026-04-23 Cleaned up the models folder abit
    [BodyDraft3Part1.stl, BodyDraft3Part2.stl, BodyFinalPart1.stl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]
2026-04-23 At this point I am really just trying to polish everything up good progress on that though.
    [BarrelRollv2.blend, FinalAssembly (1).step, FinalAssemblyV2 (1).stl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]
2026-04-24 Added pcb design elements.
    [PCB.blend, barrel-roll.kicad_pcb]
2026-04-25 Worked on the readme and adding some silkscreen art onto the pcb
    [barrel-roll-B_Cu.gbr, barrel-roll-B_Mask.gbr, barrel-roll-B_Paste.gbr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]
2026-04-26 Tried to create a rf recever
    [RFpuck_pro.kicad_sch, SX1280IMLTRT.step, Untitled.kicad_sch]
2026-04-29 Organized the repo
    [BarrelRollv2.blend, BodyDraft3Part1 copy.3mf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]
2026-04-30 Updated poster, readme, and render
    [BarrelRollV3.blend, FinalAssembly (2).step, FinalAssembly.step]
2026-05-02 Updated PCB to have a DIP version and improved readme.
    [BarrelRoll.blend, BarrelRollV3.blend, BarrelRollv2.blend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]
2026-05-02 Added BOMs
    [BOM.csv, BarrelRollerBOM.csv, BarrelRollerBOMDIP.csv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]
2026-05-02 Updated readme and organized the repo slightly
    [BodyDraft3Part1 copy.3mf, BodyDraft3Part1.3mf, BodyDraft3Part1LessWeight.3mf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]
2026-05-10 Worked on redoing the render for barrel roll
    [BOM.csv, BarrelRollV3 copy.blend, BarrelRollV3.blend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]
2026-05-11 Worked on the renders
    [BarrelRollV3 copy.blend, BarrelRollV3.blend]
2026-05-12 Worked on blender
    [BarrelRollV3 copy.blend, BarrelRollV3.blend]
2026-05-13 WOrked on the assembly instructions
    horrible progress
    [barrel-roll-B_Cu.gbr, barrel-roll-B_Mask.gbr, barrel-roll-B_Paste.gbr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]
2026-05-17 Updated renders
    [BarrelRollV3 copy.blend, BarrelRollV3.blend]
2026-05-18 Polished the repo and got the finalized .step files for 3d pritners
    [BarrelRollV3 copy.blend, BodyFinalPart1.step, BodyFinalPart2.step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]
2026-05-20 Worked on the readme of the barrel roll
    [BarrelRollV3 copy.blend]
2026-05-20 Wrapped up readme
    [shaft.step]
2026-06-07 Updated Gerbers
    [Main.3mf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]
